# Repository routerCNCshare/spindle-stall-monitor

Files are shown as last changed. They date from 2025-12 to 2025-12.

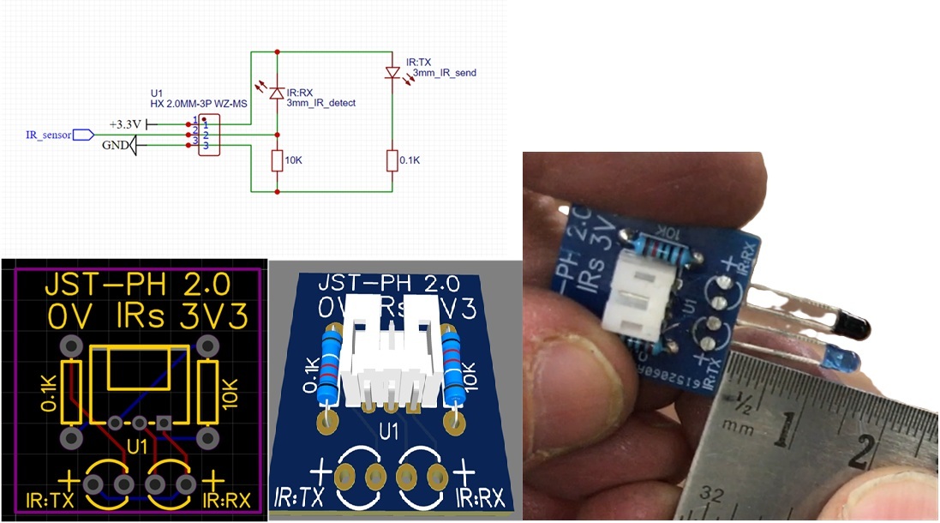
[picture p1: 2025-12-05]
Sensor_PCB/Sensor_Build.jpg

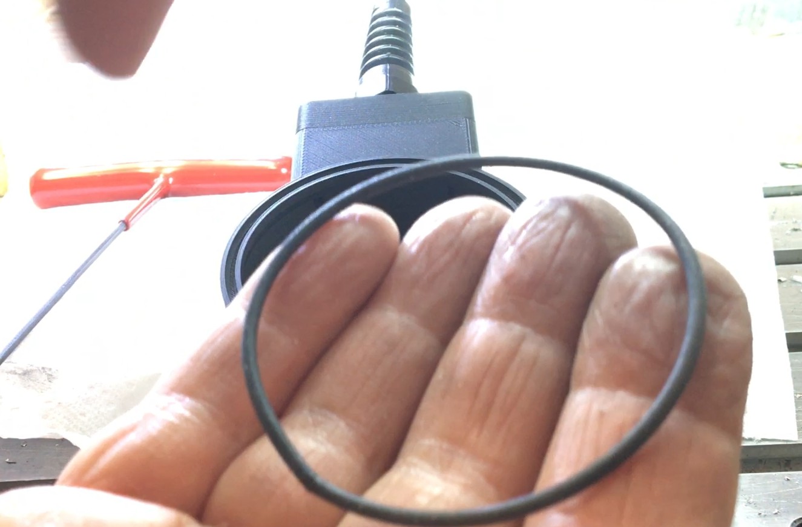
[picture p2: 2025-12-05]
3D_printer_files/Assembly_pictures/2mm_O_ring.jpg

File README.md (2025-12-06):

# spindle-stall-monitor
CNC SPINDLE STALL DETECTION SYSTEM

This is a DIY system to detect a stall condition by monitoring the CNC spindle rpm, and the inverter demand rpm, and then triggering an e-stop if the values are too far apart.
Hopefully this will prevent you breaking an end mill if it stalls in the workpiece!

Here is a link to the Stall Monitor playlist on Youtube:

https://www.youtube.com/watch?v=H4SR3w2m5jw&list=PLBhXglGlotqzxNX_20Ag2E0lQC7u3-rjH&pp=gAQB

I should mention 2 things at this point:

1- This is my first ever GitHub project so I'm learning how to upload and share things

2- Machine tools are dangerous so take all the usual precautions.  Monitor the machine at all times and don't rely soley on this e-stop system.

INTENDED SPINDLE

As released the sensor and the 3D printed parts are intended for use on a 1.5kW water cooled 'Chinese' spindle with an 80mm diameter spindle main body.
For other spindles (2kW, 3kW etc.) it would be wise to download the 3D printed main sensor housing to confirm it will fit before you go ahead with the project (or decide if you need to modify parts of the housing to suit your application).  Along with the STEP files (for 3D printing ) I will try to upload the IGES files so you can load into your favourite CAD programme as a basis to create a custom part.

INTENDED INVERTER / VFD

The inverter signal is configured to run from a Huanyang 1.5kW VFD using the 10V PWM output from the V0 and ACM outputs.  Other similar low cost inverters with a 10V PWM output are likely to work.

SKILL LEVEL

I would rate this as a medium/advanced skill level since you will need to be able to:

Order your own PCBs (using the Gerber files provided)

Order you own electronic components using the BOM list

Be able to solder components using the completed PCB pictures provided

Make up custom wiring looms to suit your application (cable between main board and display, cable between main board and sensor)

Be able to diagnose any issues along the way

Have access to a reasonable 3D printer

Be able to install Arduino IDE software to download the code along with libraries for: <Arduino.h>, <LiquidCrystal.h>, <Preferences.h>

You must also be able to add ESP32 to the board manager in the IDE software, and select "ESP32-WROOM-DA Module" as the board

I had to Google how to do this last step to get the IDE to talk to the ESP32 board and flash code onto it

HELP

As a one man hobbyist with a day job and family I may be able to help but it will be limited help (best posted on the YouTube video comments for this video series)

Have fun!

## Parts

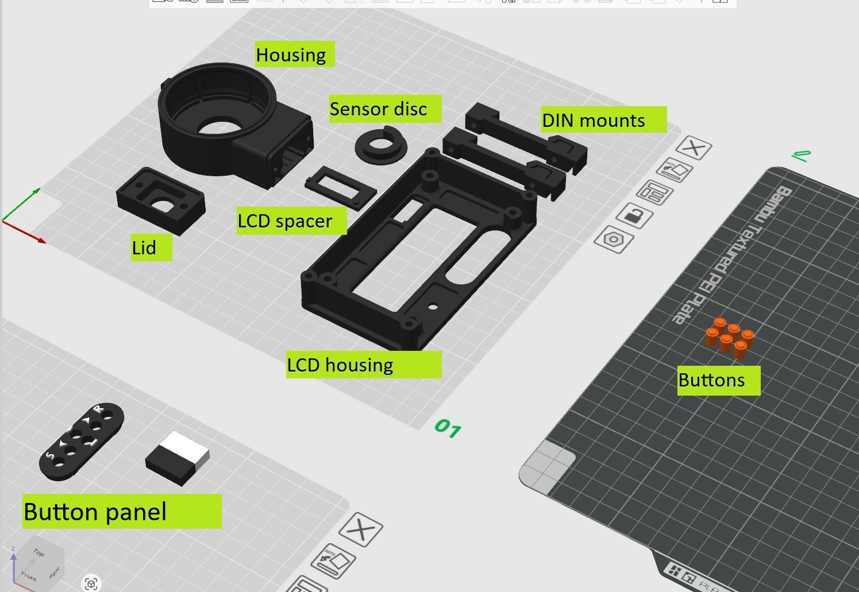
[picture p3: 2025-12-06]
3D_printer_files/Assembly_pictures/3D_parts_overview_V2.jpg

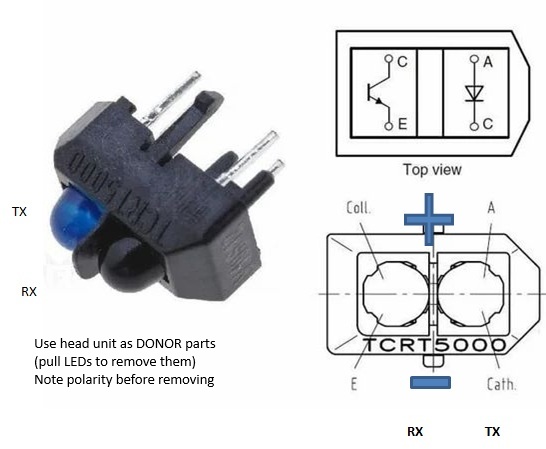
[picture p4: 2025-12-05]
Sensor_PCB/Sensor_Build_Donor_Parts.jpg

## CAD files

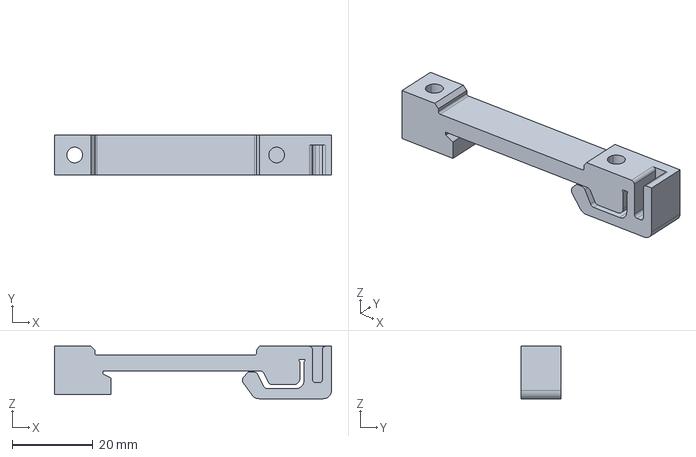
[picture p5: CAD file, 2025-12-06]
3D_printer_files/STEP/DIN_brkt_main_V2.stp
68.6 x 10.0 x 13.0 mm

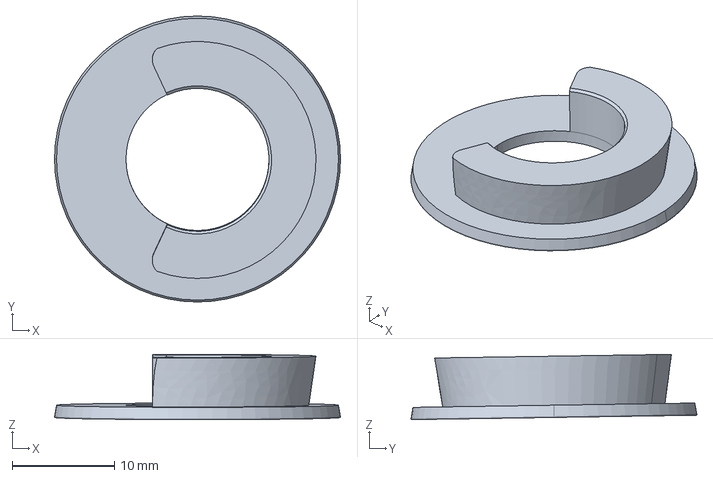
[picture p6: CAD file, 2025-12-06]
3D_printer_files/IGES/SensorDisc_v9.igs
28.0 x 28.0 x 6.39 mm

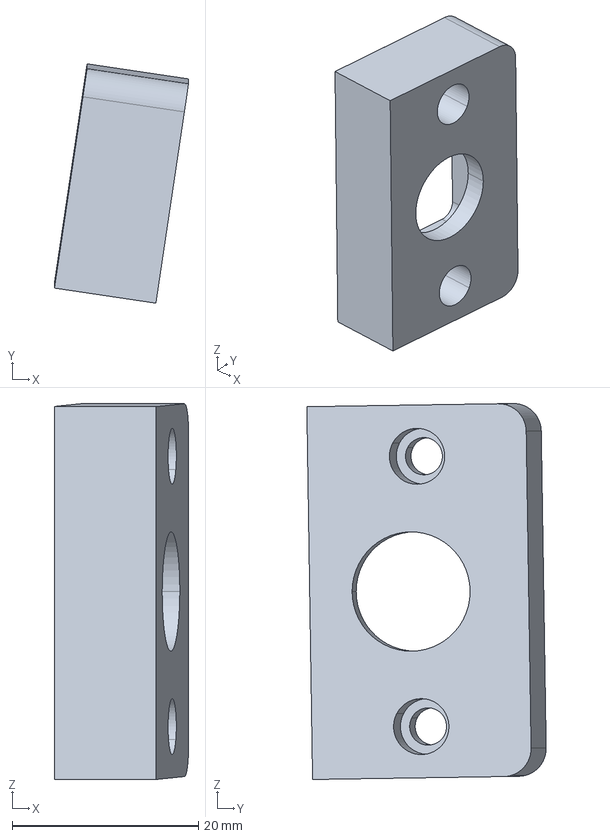
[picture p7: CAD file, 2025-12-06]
3D_printer_files/STEP/Housing_Lid_V12.stp
14.4 x 25.7 x 40.3 mm

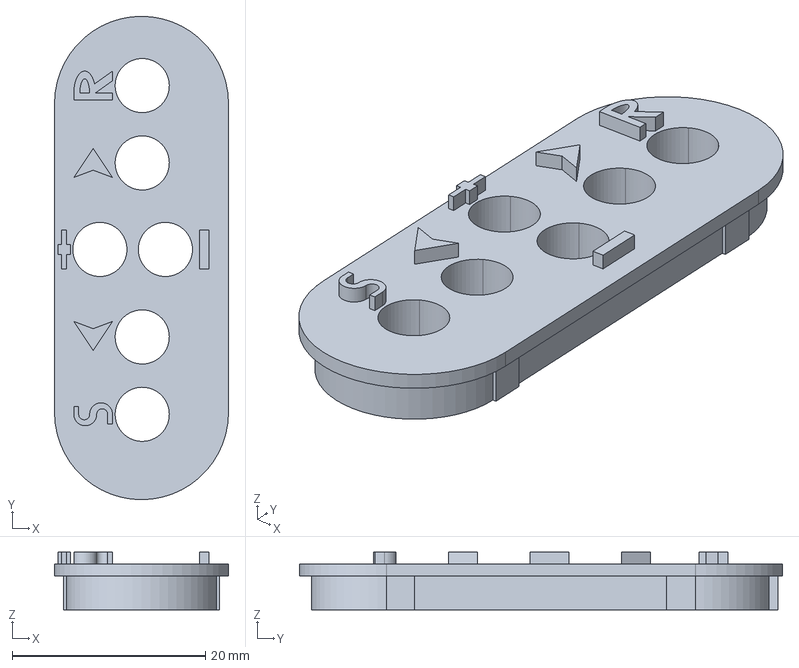
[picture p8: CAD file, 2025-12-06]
3D_printer_files/STEP/Button_Panel_V2.stp
18.0 x 50.0 x 5.98 mm

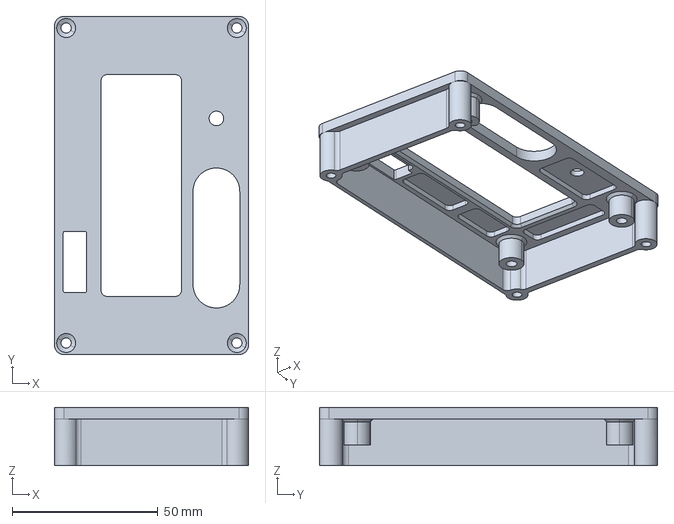
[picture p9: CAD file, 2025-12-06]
3D_printer_files/STEP/LCD_display_mounting_V1.stp
66.5 x 116.0 x 20.0 mm

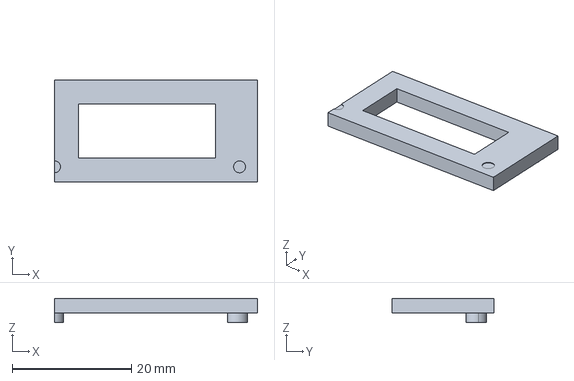
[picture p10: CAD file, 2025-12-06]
3D_printer_files/STEP/LCD_Spacer_V1.stp
34.0 x 17.0 x 4.10 mm

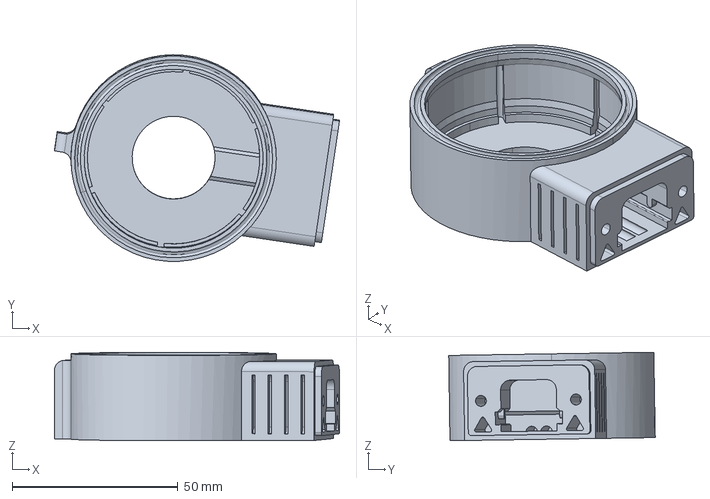
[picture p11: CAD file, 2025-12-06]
3D_printer_files/STEP/IR_Housing_V14.stp
86.0 x 62.3 x 26.7 mm

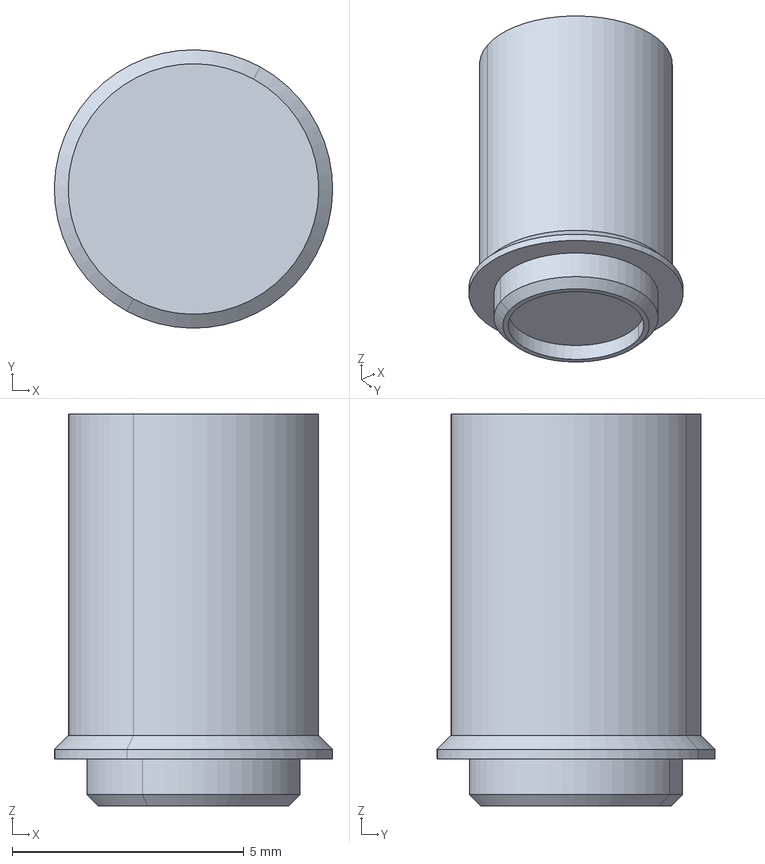
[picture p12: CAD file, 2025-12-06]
3D_printer_files/STEP/Button_V1.stp
6.00 x 6.00 x 8.45 mm

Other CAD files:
3D_printer_files/STEP/SensorDisc_V14.stp
3D_printer_files/IGES/Housing_Lid_v12.igs
3D_printer_files/IGES/IR_Housing_V14.igs

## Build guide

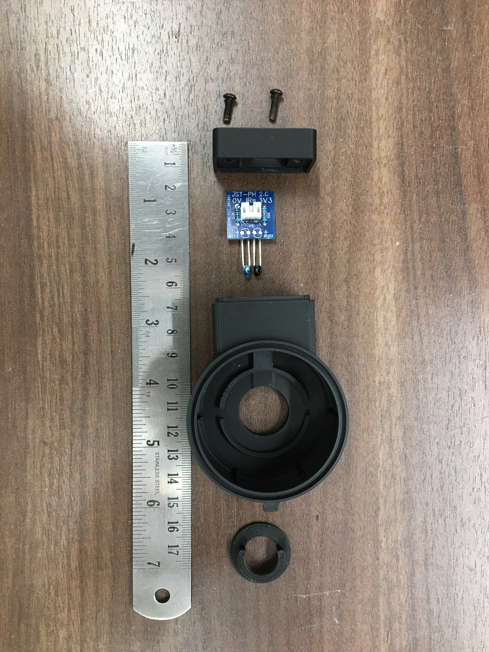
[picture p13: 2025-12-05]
Sensor_PCB/Housing_Assembly.JPG

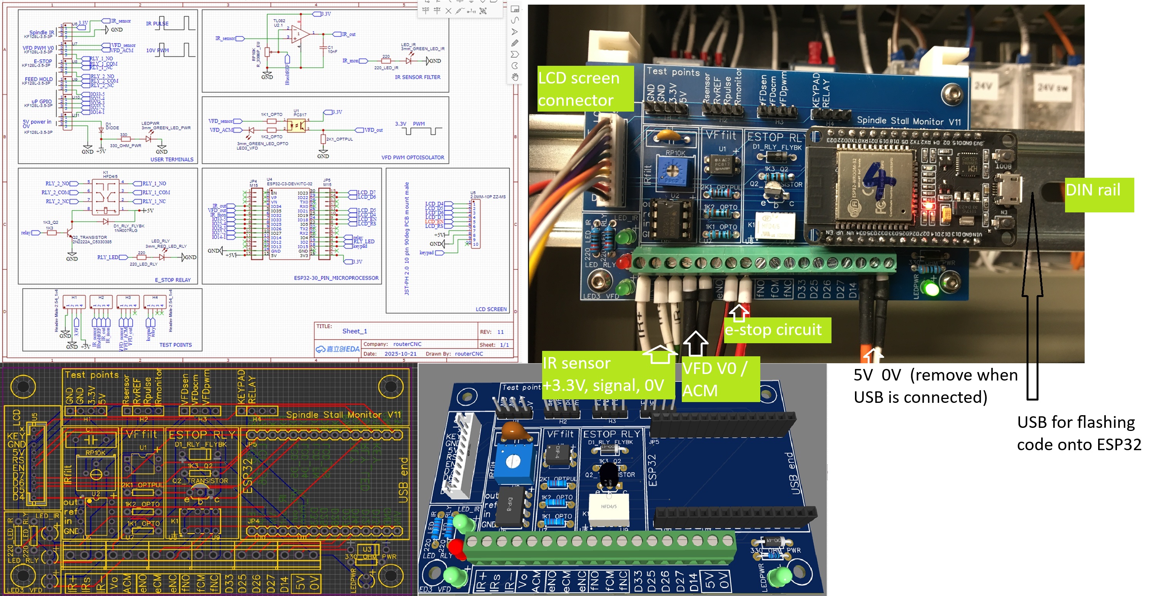
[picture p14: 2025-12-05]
Main_PCB/MainPCB_Build.jpg

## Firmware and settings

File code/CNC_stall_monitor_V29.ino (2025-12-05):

// include libraries
#include <Arduino.h>
#include <LiquidCrystal.h>  // LCD display library
#include <Preferences.h>    // preferences library (non-volatile memory to store user variables)

// initialize the library with the numbers of the interface pins
LiquidCrystal lcd(18, 5, 19, 21, 22, 23);  // RS=18, Enable=5, D4=19, D5=21, D6=22, D7=23, VSS=GND, VDD > 5V   < ESP32 board #3

// version record
//V15.  Added average rpm calculations to smooth the readings
//V16.  Added basic menu functions
//V17.  Added improved menu functions
//V18.  Tuning for estop, better default settings, better algorithm
//V19.  Improve e-stop logic
//V20.  Menu tidied.  Factory restore feature added.
//V21.  Initial code for storing user variables in non-volatile memory
//V22.  Stable code for storing user variables in non-volatile memory
//V23.  New prototype board, split main and LCD.  New user key values.  More stable VFD readings.
//V24.  Setup to use Hall Effect Sensor (instead of IR sensor)
//V25.  Some further improvements
//V26.  Tidying up the code, cleaning up menu options, and making it e-stop quicker
//V27.  More tidying up the code, better load sensing display, more tuning
//V28.  Key input values set for 5V (rather than USB 4.88V)

// version for display
const int software_version = 29;



///////////////////////////////////////////////////////////////////////////
//              Configure processor interface pins and user keys         //
///////////////////////////////////////////////////////////////////////////
// assign pins
const int IR_SENSOR_PIN = 34;      // define the pin where the IR sensor is connected
const int BUTTON_PIN_A0 = 15;      // read button interface:  nothing = 4096, sel= 3580, left= 2150 , right= 0,  up= 490 , down= 1330
const int BUTTON_TOLERANCE = 100;  // +- range to look for button press
const int VFD_PWM_PIN = 35;        // define pin for reading PFD PWM signal
const int IR_MONITOR_PIN = 32;     // recreate PWM signal as monitor output
const int ESTOP_RELAY_PIN = 4;     // define pin to control e-stop relay
const int ESTOP_LED_PIN = 2;       // define pin for relay LED
const int VFD_RPM_PIN = 25;        // DAC analog output of VFD RPM
const int RPM_PIN = 26;            // DAC analog output of spindle RPM

// declare user variables for key presses
// set for 5V input (scale if supply voltage is less)
double read_user_pin = 0;  // analogue value for key presses
int system_state = 0;      // store system state: 0 = unknown, 1 = idle, 2= accelerating, 3 = decelerating, 4 = running, 8 = feed hold, 9 = e-stop
int KEY_UP = 360;
int KEY_DOWN = 1140;
int KEY_LEFT = 1892;
int KEY_RIGHT = 0;
int KEY_SELECT = 3071;
int KEY_NO = 4095;         // 5V full range






///////////////////////////////////////////////////////////////////////////////////
//                           declare menu structure                              //
///////////////////////////////////////////////////////////////////////////////////
//
struct menu_structure {
  String menu_label;       // field #1 (name)
  int menu_value;          // field #2 (user value)
  int menu_inc_dec;        // field #3 (inc or dec amount)
  int menu_value_max;      // field #4 (max value allowed)
  int menu_value_min;      // field #5 (min value allowed)
  int menu_factory_value;  // field #6 (factory reset value)
};
// Create an array of Menu_Structure defined structures containing factory reset values (text", user value, inc/dec step, max value, min value, factory default)
menu_structure menu[] = {
  // spindle sampling for rpm calculation and follow error (lower value = less follow error allowed = more sensitivity)
  { "1:SampleTime(ms)", 250, 5, 2000, 25, 250 },  // menu item #0
  { "2:FollowError%", 20, 5, 100, 5, 20 },        // menu item #1
  // rpm calculation fine tuning
  { "3:SpinRpmScale", 100, 1, 150, 10, 100 },  // menu item #2
  { "4:VFD RpmScale", 100, 1, 150, 10, 100 },  // menu item #3
  // parameters to determine 'run', 'accel', or 'decel'
  { "5:RpmDecelThresh", -400, 5, -50, -1000, -400 },  // menu item #4
  { "6:RpmAccelThresh", 400, 5, 1000, 50, 400 },      // menu item #5
  { "7: Menu end", 0, 0, 0, 0, 0 }                    // menu item #6
};
const int number_of_menu_rows = sizeof(menu) / sizeof(menu[0]);
// function prototype declaration
void menu_subroutine(menu_structure menu[], int menu_size);
///////////////////////////////////////////////////////////////////////////////////

// Set up preferences library (where user data is stored)
Preferences preferences;





///////////////////////////////////////////////////////////////////////////////////
//                           declare variables                                   //
///////////////////////////////////////////////////////////////////////////////////
// IR sensor pulse counter from spindle
double spindle_pulse_analog = 0;      // read analog state of spindle input from Hall sensor op amp (then invert it)
int spindle_pulse_state = 0;          // read IR_Sensor pulse state
int spindle_last_pulse_state = 0;     // store previous pulse state
unsigned long spindle_last_time = 0;  // store previous spindle time
double spindle_debounce_time = 0;     // spindle pulse debounce time in milliseconds

// spindle rpm calculation
double pulse_count = 0;         // count of IR sensor pulses
unsigned long Master_Time = 0;  // current time in milliseconds for tracking sampling intervals
double rpm = 0;                 // calculated rpm
double rounded_rpm = 0;
double rpm_last_measurement = 0;  // previous rpm measurement to help calculate acceleration
double rpm_last_time = 0;         // last time the RPM was calculated
double min_rpm = 500;             // minimum rpm to calculate system state (assume not running if rpm below this value)
double pulse_per_rpm = 2;         // number of pulses per rpm (rising and falling pulses are both counted, so use 2 for a single white strip)
bool system_active = false;       // boolean flag to show if stall system is active.  Off at low rpm or if spindle has not started yet.

// user defined variables (stored in memory)
double rpm_sample_time = 250;            // how long to sample IR sensor pulses (in milliseconds)
double delta_rpm_stall = 20;             // min % of actual Vs demand rpm.  If actual rpm is less than this % of demand, then may be stalling.
double spindle_scale = 100;              // scaling to fine tune spindle rpm value
double PWM_scale = 100;                  // scale to fine tune PWM to RPM mapping
double acceleration_upper_limit = 400;   // acceleration upper trigger limit
double acceleration_lower_limit = -400;  // acceleration lower trigger limit

// spindle acceleration calculation
double acceleration = 0;  // current acceleration

// VFD PWM variables
int vfd_PWM_signal = 0;            // VFD PWM signal value
int vfd_PWM_signal_last_time = 0;  // store PMW signal from last time
double vfd_PWM_rpm = 0;            // VFD PWM converted to rpm
double rounded_vfd_PWM_rpm = 0;

// PWM duty cycle variables
double highTime = 0;              // counter in microseconds for how long in HIGH state
double lowTime = 0;               // counter in microseconds for how long in HIGH state
double lastTime = 0;              // record last time to work out delta time
double totalTime = 0;             // store total time for sum of high and low times
int PWM_pulse_state = 0;          // 0 = low, 1= high flip flop
double dutyCycle = 0;             // calculate duty cycle 0 - 100%
static double lastPrintTime = 0;  // how long since last display and calculation update
double currentTime = 0;           // store current time at this moment


// load meter variables
double delta_rpm = 0;        // difference between actual rpm and VFD demand rpm
double load_meter_bars = 0;  // how many load bars to display on the LCD (depending on following error %)
byte FullSquare[8] = {       // custom graphic for load bar
  B11111,
  B11111,
  B11111,
  B11111,
  B11111,
  B11111,
  B11111,
  B11111
};
byte LoadMeter[8] = {  // custom graphic for load bar outline
  B11111,
  B00000,
  B00000,
  B00000,
  B00000,
  B00000,
  B00000,
  B11111
};






////////////////////////////////////////////////////////////////////////////
//                              set up systems                            //
////////////////////////////////////////////////////////////////////////////
void setup() {

  // LCD display
  lcd.begin(16, 2);             // columns and rows
  lcd.clear();                  // clear LCD screen and reset cursor to 0,0
  lcd.setCursor(0, 0);          // set cursor top of display
  lcd.print("SpindleGuard");    // display splash message with version number
  lcd.setCursor(0, 1);          // display splash message with version number
  lcd.print("V");               // display splash message with version number
  lcd.print(software_version);  // display splash message with version number
  delay(1000);                  // wait 1 second to allow user to read splash message
  lcd.clear();                  // clear LCD screen and reset cursor to 0,0
  // create a new LCD characters
  lcd.createChar(0, FullSquare);
  lcd.createChar(1, LoadMeter);

  // pin configuration
  pinMode(IR_SENSOR_PIN, INPUT);       // Set up the IR sensor pin as input
  pinMode(IR_MONITOR_PIN, OUTPUT);     // monitor output pin to check PWM triggering correctly
  digitalWrite(IR_MONITOR_PIN, LOW);   // set monitor pin LOW as start point
  pinMode(BUTTON_PIN_A0, INPUT);       // set up the pin to read keypad button presses
  pinMode(VFD_PWM_PIN, INPUT);         // read VFD PWM signal
  pinMode(ESTOP_RELAY_PIN, OUTPUT);    // relay pin defined as output
  digitalWrite(ESTOP_RELAY_PIN, LOW);  // ensure estop relay control pin is not active when starting
  pinMode(ESTOP_LED_PIN, OUTPUT);      // declare pin2 as output for relay LED
  digitalWrite(ESTOP_LED_PIN, LOW);    // ensure relay LED off at start






  ///////////////////////////////////////////////////////////////////////////////////
  // check if factory reset required - is user holding down 'select/menu' key?     //
  ///////////////////////////////////////////////////////////////////////////////////

  preferences.begin("user_data", false);                                                                           // Open Preferences with namespace "user_data"
  read_user_pin = analogRead(BUTTON_PIN_A0);                                                                       // read button press value
  if (((read_user_pin < (KEY_SELECT + BUTTON_TOLERANCE)) && (read_user_pin > (KEY_SELECT - BUTTON_TOLERANCE)))) {  // is user pressing select/menu ?

    // pressed menu/select button so start factory reset process
    lcd.setCursor(0, 0);                                                           // move cursor
    lcd.print("**FACTORY RESET**");                                                // show message
    read_user_pin = analogRead(BUTTON_PIN_A0);                                     // read button state
    while (read_user_pin < KEY_NO) { read_user_pin = analogRead(BUTTON_PIN_A0); }  // wait for button to be released
    for (int i = 0; i <= number_of_menu_rows; i++) {                               // loop through and reset array values to factory
      menu[i].menu_value = menu[i].menu_factory_value;                             // load user values from FACTORY into 'value' field of array structure
    }                                                                              // loop back
    preferences.clear();                                                           // clear all values in current preferences area in non-volatile memory
    saveUserData();                                                                // store FACTORY values into non-volatile memory (overwriting user values)

    // display 'progress bar' (really just showing user that something has happened)
    lcd.setCursor(0, 1);
    for (int i = 1; i <= 15; i++) {
      lcd.write(byte(0));  // Display the full square character
      delay(125);
    }
    lcd.clear();  // clear LCD screen
  } else

    ////////////////////////////////////////////////////
    // otherwise load user stored values from memory  //
    ////////////////////////////////////////////////////
    // check if preferences library exists (1st ever run will not have a preference library stored)
    if (preferences.getInt("key_value_0", -1) != -1) {
      // load preference library into array structure
      lcd.setCursor(0, 0);            // move cursor
      lcd.print("load user values");  // display user message
      loadUserData();                 // load values from non-volatile memory into array structure containing user values

      // display 'progress bar' (really just showing user that something has happened)
      lcd.setCursor(0, 1);
      for (int i = 1; i <= 15; i++) {
        lcd.write(byte(0));  // Display the full square character
        delay(125);
      }
      lcd.clear();  // clear LCD screen
    } else {
      // no preferences library set up so load defaults (actually does nothing, so firmware factory values are retained)
      lcd.setCursor(0, 0);         // move cursor
      lcd.print("load defaults");  // display user message

      // display 'progress bar' (really just showing user that something has happened)
      lcd.setCursor(0, 1);
      for (int i = 1; i <= 15; i++) {
        lcd.write(byte(0));  // Display the full square character
        delay(125);
      }
      lcd.clear();  // clear LCD screen
    }

  // load values from array structure into main variables
  rpm_sample_time = menu[0].menu_value;           // rpm sample time in milliseconds
  delta_rpm_stall = menu[1].menu_value;           // threshold as % of demand rpm for stall monitoring (e.g. 70% means if actual rpm < 70% of demand rpm system might be stalling)
  spindle_scale = menu[2].menu_value;             // scaling factor to adjust spindle rpm calculation
  PWM_scale = menu[3].menu_value;                 // scaling factor to adjust rpm calculation for VFD demand rpm
  acceleration_lower_limit = menu[4].menu_value;  // lower rpm limit to display "accel" on LCD
  acceleration_upper_limit = menu[5].menu_value;  // upper rpm limit to display "decel" on LCD



  /////////////////////////////////////////////////////////////////////////////
  //                       standby until key pressed                         //
  /////////////////////////////////////////////////////////////////////////////
  lcd.clear();
  lcd.setCursor(0, 0);
  lcd.print("*****offline*****");
  lcd.setCursor(0, 1);
  lcd.print(">SELECT");
  read_user_pin = analogRead(BUTTON_PIN_A0);  // read key press value
  while ((read_user_pin > (KEY_SELECT + 20)) || (read_user_pin < (KEY_SELECT - 20))) {
    read_user_pin = analogRead(BUTTON_PIN_A0);
    lcd.setCursor(12, 1);
    lcd.print(read_user_pin);
    lcd.print("   ");
  }             // read button press value
  lcd.clear();  // clear display
  delay(500);   // wait for key to be released
}
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

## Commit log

2025-12-05 Create Gerber_MainPCB_V11
2025-12-05 Create Sensor_PCB
2025-12-05 Create Sensor Build Notes
2025-12-05 Rename Sensor Build Notes to Sensor Bill Of Materials
2025-12-05 Update Sensor Bill Of Materials
2025-12-05 Rename Sensor_Build_Donor_Parts.jpg to Sensor_Build_Donor_TXRX_head
    Use this IR TX / RX head unit as donor LED parts
2025-12-05 Update and rename Readme_LCD_PCB to LCD Bill Of Materials
2025-12-05 Update LCD Bill Of Materials
2025-12-05 Create Main PCB Bill Of Materials
2025-12-05 Update Main PCB Bill Of Materials
